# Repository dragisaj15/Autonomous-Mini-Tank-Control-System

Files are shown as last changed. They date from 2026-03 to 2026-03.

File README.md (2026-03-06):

# Autonomous Mini Tank Control System
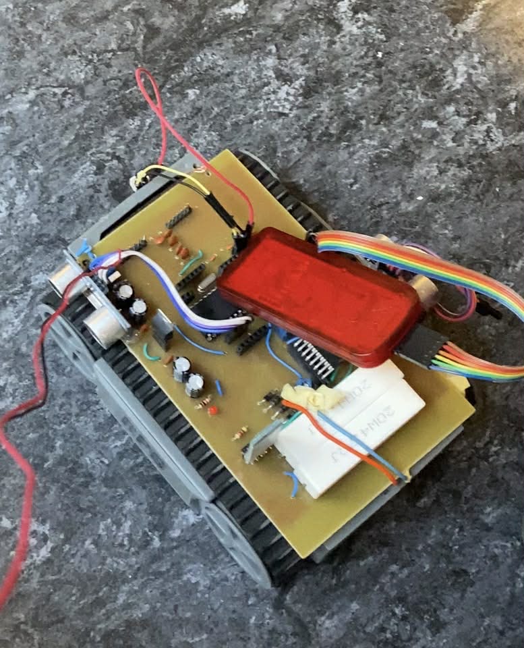
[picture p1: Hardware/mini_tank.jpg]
Assembled Mini Tank


##  Project Overview
This project involves the development of an autonomous, tracked robotic vehicle (Mini Tank) controlled by a **dsPIC30F4013** microcontroller. The system is designed to navigate its environment independently by constantly scanning for obstacles and making real-time pathfinding decisions.

The tank integrates both analog infrared and digital ultrasonic sensors to calculate distances, uses PWM to drive the motors, and is remotely activated via a Bluetooth serial (UART) connection.
## Custom PCB Design (Altium Designer)

To accommodate all necessary components, including the microcontroller, motor drivers, and sensor arrays, a custom double-sided printed circuit board (PCB) was designed.

### 2D PCB Routing
This view demonstrates the trace routing across the top (red) and bottom (blue) layers, including necessary via placements and component footprints.
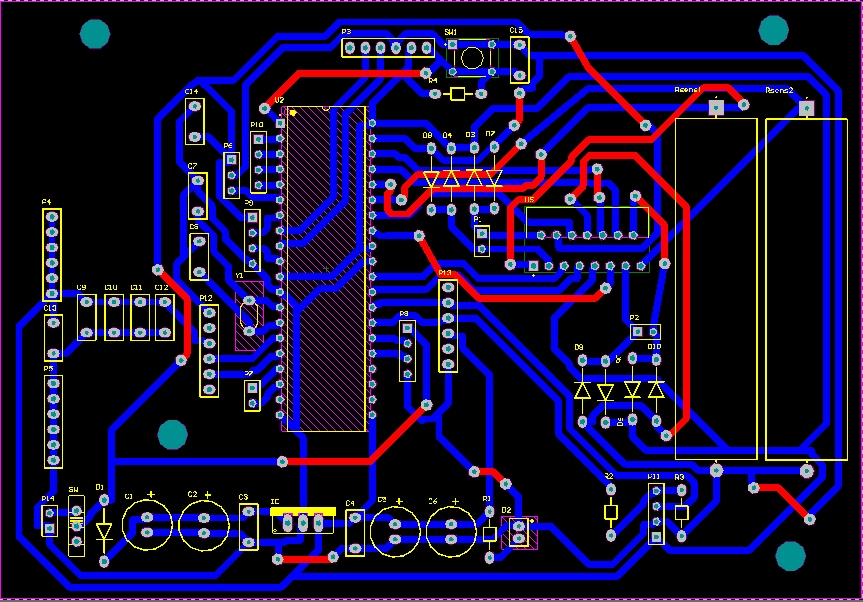
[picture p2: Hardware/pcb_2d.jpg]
2D PCB Routing


### 3D Board Visualization
The 3D model was generated to verify component placement and ensure no mechanical collisions prior to manufacturing.
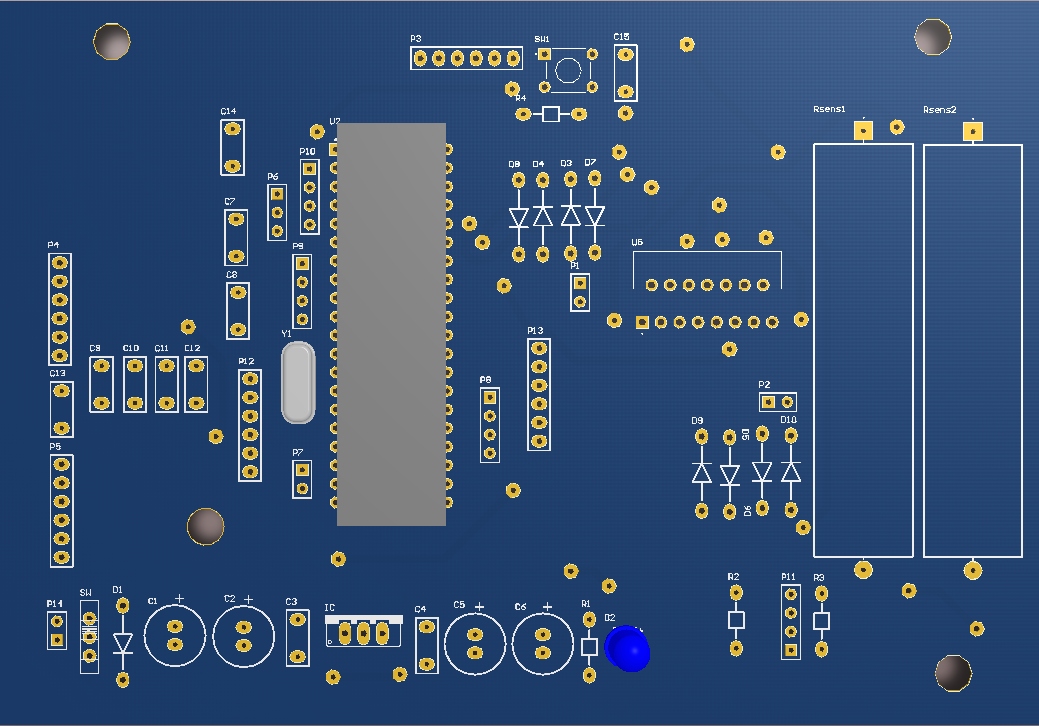
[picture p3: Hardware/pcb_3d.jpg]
3D PCB Model


##  Hardware Architecture
*   **Microcontroller:** Microchip dsPIC30F4013 (10MHz crystal, `XT_PLL4`)
*   **Sensors:**
    *   **1x Sharp GP2Y** (Analog IR Distance Sensor) - Front obstacle detection
    *   **2x HC-SR04** (Digital Ultrasonic Sensors) - Left and right obstacle detection
*   **Actuators:**
    *   DC Motors (Track drive system controlled via PWM)
*   **Communication:** Bluetooth Module (HC-05/HC-06) connected via UART2

##  Firmware & Peripheral Utilization (C Language)
The firmware relies heavily on bare-metal C programming, utilizing multiple hardware peripherals to ensure non-blocking, real-time execution:
*   **Hardware Timers & Interrupts:**
    *   `TMR1` & `TMR2`: System tick and precise delay generation (milliseconds & microseconds).
    *   `TMR3`: Base timer for Motor PWM generation.
    *   `TMR4` & `TMR5`: Dedicated timers for measuring the precise `ECHO` pulse width from the HC-SR04 sensors.
*   **12-bit ADC Module:** Configured with `_ADCInterrupt` to continuously read the analog voltage from the Sharp GP2Y sensor and convert it to distance (cm) using a non-linear power function.
*   **UART2 Module:** Configured to receive start commands (`"ON"`) via Bluetooth and transmit debugging telemetry back to the user.

##  Navigation Logic
1.  **System Standby:** The tank waits for the `"ON"` command via Bluetooth UART.
2.  **Forward Movement:** As long as the front IR sensor reads a clear path (`> 12 cm`), the tank moves forward.
3.  **Obstacle Avoidance:** If an obstacle is detected in front (`< 12 cm`), the tank stops.
4.  **Path Decision:** It compares the distances measured by the Left and Right HC-SR04 sensors. The tank will automatically rotate towards the side with more open space, recalculate, and resume forward movement.

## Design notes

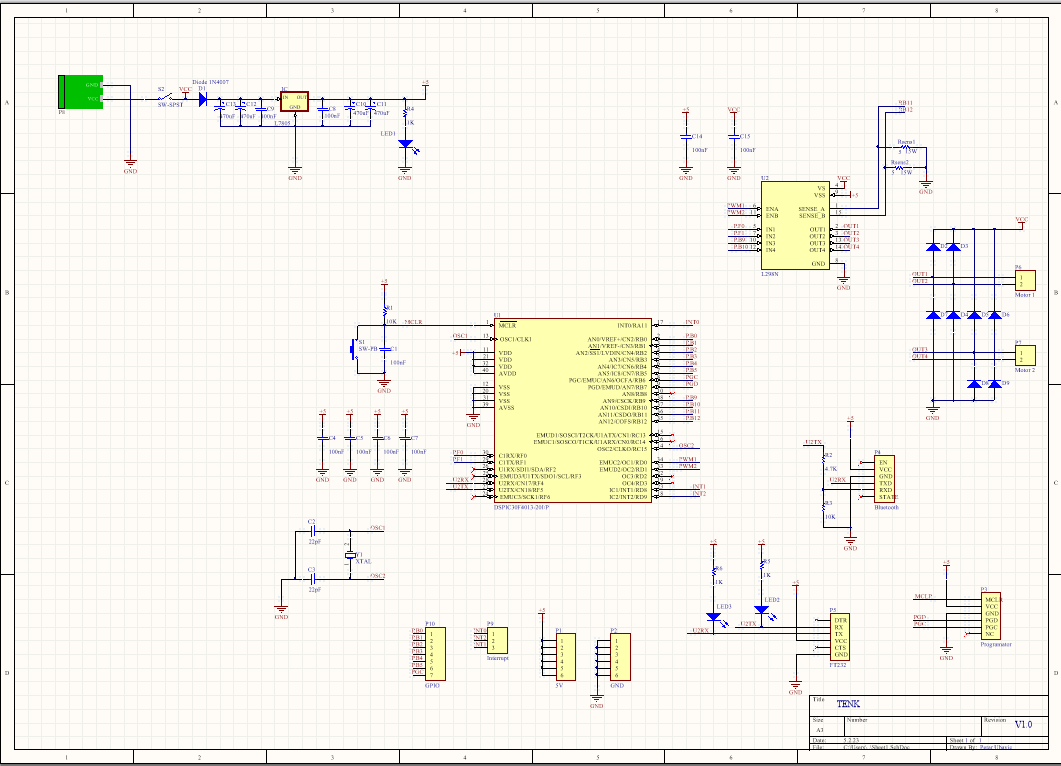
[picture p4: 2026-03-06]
Hardware/Schematic.png

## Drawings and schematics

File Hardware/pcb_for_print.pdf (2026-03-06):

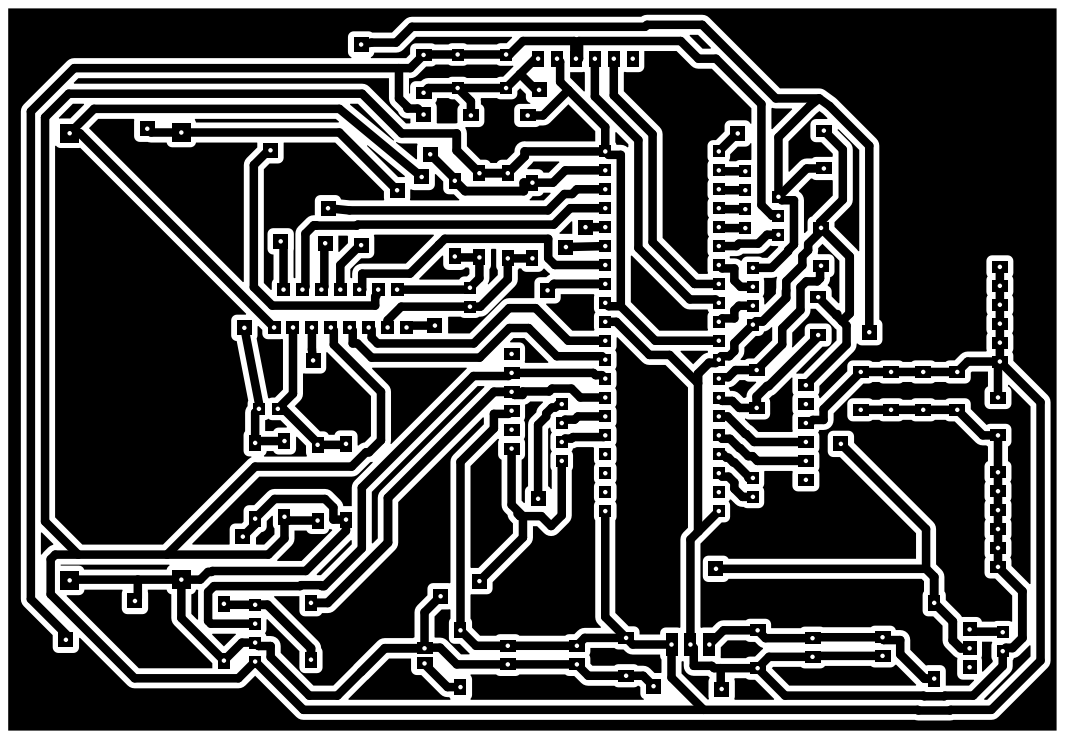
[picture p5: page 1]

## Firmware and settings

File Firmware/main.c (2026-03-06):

#include <p30fxxxx.h>
#include <stdio.h>
#include <stdlib.h>
#include <math.h>
#include "adc.h"
#include "timer.h"
#include "uart.h"
#include "hc_senzor.h"
#include "outcompare.h"
#include "pwm.h"
#include "upravljanje_motora.h"

_FOSC(CSW_FSCM_OFF & XT_PLL4); // Instruction clock is the same as the 10MHz crystal
_FWDT(WDT_OFF);                // Disable Watchdog Timer

#define SPEED_OF_SOUND (0.0343) // cm/s
#define INSTRUCTION_CLOCK_PERIOD (0.1) // us

unsigned int raw_adc0, gp2y_flag, sys_flag;
unsigned int temp_delay, temp_delay1, temp_delay2, rx_index, tempRX, temp0, analog_val;
unsigned int analog_read, echo_pulse;
int rx_buf[1];

static unsigned char timeout_sensor_2 = 0;
static float measured_distance_2 = 0;
static unsigned char timeout_sensor_1 = 0;
static float measured_distance_1 = 0;
static float distance_gp2y = 0;
static float voltage_gp2y = 0;
static int counter_us, counter_ms;

// TIMER 1 INTERRUPT ROUTINE - Every 1ms
void __attribute__ ((__interrupt__, no_auto_psv)) _T1Interrupt(void) 
{
    TMR1 = 0;
    counter_ms++;
    IFS0bits.T1IF = 0;     
}

// TIMER 2 INTERRUPT ROUTINE - Every 1us
void __attribute__ ((__interrupt__, no_auto_psv)) _T2Interrupt(void) 
{
    TMR2 = 0;
    counter_us++;
    IFS0bits.T2IF = 0;     
}

// TIMER 3 INTERRUPT ROUTINE - For PWM generation
void __attribute__ ((__interrupt__, no_auto_psv)) _T3Interrupt(void) 
{
    TMR3 = 0;
    IFS0bits.T3IF = 0;     
}

// TIMER 4 INTERRUPT ROUTINE - For the second digital ultrasonic sensor
void __attribute__ ((__interrupt__, no_auto_psv)) _T4Interrupt(void) 
{
    TMR4 = 0;
    ECHO_PIN_2 = 0;
    timeout_sensor_2 = 1;
    IFS1bits.T4IF = 0;     
}

// TIMER 5 INTERRUPT ROUTINE - For the first digital ultrasonic sensor
void __attribute__ ((__interrupt__, no_auto_psv)) _T5Interrupt(void) 
{
    TMR5 = 0;
    ECHO_PIN = 0;  
    timeout_sensor_1 = 1;
    IFS1bits.T5IF = 0;     
}

// FUNCTION PROTOTYPE - Delay in ms
static void DelayMs(int time_ms);
// FUNCTION PROTOTYPE - Delay in us
static void DelayUs(int time_us);

// UART2 INTERRUPT ROUTINE - For Bluetooth communication
void __attribute__((__interrupt__)) _U2RXInterrupt(void) 
{
    IFS1bits.U2RXIF = 0;
    tempRX = U2RXREG;
    if(tempRX != 0){
        rx_buf[rx_index] = tempRX;
        if(rx_index < 2) {
            rx_index++;
        } 
        else {
            rx_index = 0;
        }
    }
} 

// ADC INTERRUPT ROUTINE
void __attribute__((__interrupt__)) _ADCInterrupt(void) 
{
    raw_adc0 = ADCBUF0; // Read from GP2Y sensor channel
    analog_val = raw_adc0;
                                      
    IFS0bits.ADIF = 0;
} 

// DELAY FUNCTION - milliseconds
static void DelayMs(int time_ms)
{
    counter_ms = 0;
    T1CONbits.TON = 1;
    while(counter_ms < time_ms);
    T1CONbits.TON = 0;
}
                
// DELAY FUNCTION - microseconds           
static void DelayUs(int time_us)
{
    counter_us = 0;
    T2CONbits.TON = 1;
    while(counter_us < time_us);
    T2CONbits.TON = 0;
}      

// READ VOLTAGE FROM ANALOG GP2Y SENSOR AND CONVERT TO DISTANCE (IN CM)
float ReadDistance1GP2Y(){  
    // Convert analog ADC value to voltage
    voltage_gp2y = analog_val * (5.0 / 4095.0);

    // Convert voltage to distance in centimeters (based on GP2Y datasheet curve)
    distance_gp2y = 27.86 * powf(voltage_gp2y, -1.15);
    
    return distance_gp2y;
}

// READ VALUE FROM FIRST ULTRASONIC SENSOR
float ReadDistance1() {
    // Generate a 10us trigger pulse
    TRIGGER_PIN = 1;
    DelayUs(3);
    TRIGGER_PIN = 0;
    DelayUs(3);
    
    // Wait for ECHO pin to go high
    while (ECHO_PIN == 0);
    TMR5 = 0;              
    IFS1bits.T5IF = 0;
    T5CONbits.TON = 1;    // Start Timer 5
    
    // Measure the width of the ECHO signal
    while (ECHO_PIN == 1);
    T5CONbits.TON = 0;  // Stop Timer 5, measurement complete
    
    unsigned int measured_time_1; 
    if(timeout_sensor_1 == 1)     // If timeout occurred (no object in range)
    {
        measured_time_1 = TMR5_period;
        timeout_sensor_1 = 0;
    }
    else                            // Signal returned successfully
    {
        measured_time_1 = TMR5;
    }
    TMR5 = 0;
   
    // Calculate distance based on speed of sound
    measured_distance_1 = (measured_time_1 * INSTRUCTION_CLOCK_PERIOD) / 2.0 * SPEED_OF_SOUND;        
    return measured_distance_1;
} 

// READ VALUE FROM SECOND ULTRASONIC SENSOR
float ReadDistance2() {
    // Generate a 10us trigger pulse
    TRIGGER_PIN_2 = 1;
    DelayUs(3);
    TRIGGER_PIN_2 = 0;
    DelayUs(3);
    
    // Wait for ECHO pin to go high
    while (ECHO_PIN_2 == 0);
    TMR4 = 0;
    IFS1bits.T4IF = 0;
    T4CONbits.TON = 1; 
    
    // Measure the width of the ECHO signal
    while (ECHO_PIN_2 == 1);
    T4CONbits.TON = 0;  // Stop Timer 4, measurement complete
    
    unsigned int measured_time_2; 
    if(timeout_sensor_2 == 1)     // If timeout occurred
    {
        measured_time_2 = TMR4_period;
        timeout_sensor_2 = 0;
    }
    else                            // Signal returned successfully
    {
        measured_time_2 = TMR4;
    }
    TMR4 = 0;

    // Calculate distance based on speed of sound
    measured_distance_2 = (measured_time_2 * INSTRUCTION_CLOCK_PERIOD) / 2.0 * SPEED_OF_SOUND;        
    return measured_distance_2;
} 

// START SYSTEM - System activates when "ON" is received via Bluetooth
void start(){
    if(rx_buf[0] == 'O' && rx_buf[1] == 'N') {
            sys_flag = 1;
            WriteUART2(10);
            RS232_putst2("STARTING"); // Notify via Bluetooth
            DelayMs(2000);
    }
}


int main(int argc, char** argv) {
    
    // Initial stabilization delays
    for(temp_delay1=0; temp_delay1<10000; temp_delay1++);
    for(temp_delay=0; temp_delay<60000; temp_delay++);
    
    sys_flag = 0;
    
    // Hardware Initializations
    Init_T1();
    Init_T2();
    Init_T3();
    Init_T4();
    Init_T5();
    
    ConfigureADCPins();
    ADCinit();
    ADCON1bits.ADON = 1; // Start AD conversion 
    
    ConfigureHC_sensor();
    initUART1();
    initUART2(); // Bluetooth UART
    initPWM();   // Motor control PWM
    
	while(1)
	{
        start();    
        
        if (sys_flag == 1) {
            
            distance_gp2y = ReadDistance1GP2Y();
            WriteUART2(10);
            
            measured_distance_1 = ReadDistance1();
            measured_distance_2 = ReadDistance2();
        
            /*
            // PRINT MEASURED SENSOR VALUES TO BLUETOOTH
            char buffer[20];
            int i;

            // Print Sensor 1 to BT
            sprintf(buffer, "Sensor 1: %.2f cm\r", (double)measured_distance_1);
            for (i = 0; i < 20; i++) {
                WriteUART2(buffer[i]);
            }
              
            // Print Sensor 2 to BT  
            sprintf(buffer, "Sensor 2: %.2f cm\r\n", (double)measured_distance_2);
            for (i = 0; i < 20; i++) {
                WriteUART2(buffer[i]);
            } 
            
            // Print GP2Y to BT
            sprintf(buffer, "Sensor GP2Y: %.2f cm\r", (double)distance_gp2y);
            for (i = 0; i < 20; i++) {
                WriteUART2(buffer[i]);
            } 
            */
       
            // NAVIGATION ALGORITHM:
            // The tank moves forward until an obstacle is detected in front.
            // When an obstacle is detected, it compares the values of the left and right sensors 
            // to decide the best direction to turn.
            
            if(distance_gp2y >= 12) {
                pravo(); // Move forward
                
            } else if (distance_gp2y < 12 && (measured_distance_2 <= measured_distance_1)){
                stani(); // Stop
                DelayMs(500);
                levo();  // Turn left
                DelayMs(1200);
                stani(); // Stop
                DelayMs(100);
                
            } else if (distance_gp2y < 12 && (measured_distance_1 < measured_distance_2)) {
                stani(); // Stop
                DelayMs(500);
                desno(); // Turn right
                DelayMs(1200);
                stani(); // Stop
                DelayMs(100);
                
            } else {
                stani(); // Stop default
            } 
        } // end if sys_flag
    } // end while    
    
    return (EXIT_SUCCESS);
}

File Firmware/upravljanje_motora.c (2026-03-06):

#include "upravljanje_motora.h"
#include "pwm.h"
#include "uart.h"
#include <p30fxxxx.h>

void pravo()
{
    
    LATFbits.LATF0=1; //za smer prvog motora
    LATFbits.LATF1=0; 
        
    LATBbits.LATB9=1; //za smer drugog motora
    LATBbits.LATB10=0; 
    
    PWM1(450); //PWM 1 i PWM 2 nisu postavljeni na iste vrednosti, jer jedan motor malo slabije radi, pa smo empirjiski dosli do ovih optimalnih vrednosti
    PWM2(480);
    
    RS232_putst2("Idem pravo");
}

void levo()
{
    //DESNI MOTOR IDE NAPRED, A LEVI NAZAD
    LATFbits.LATF0=1; //za smer prvog motora
    LATFbits.LATF1=0; 
        
    LATBbits.LATB9=0; //za smer drugog motora
    LATBbits.LATB10=1; 
    
    PWM1(480); //PWM NIJE POSTAVLJEN JEDNAKO KAKO BI MOTOR BOLJE SKRETAO
    PWM2(450);
    
    RS232_putst2("Idem levo");
}

void desno()
{
    
    LATFbits.LATF0=0; //za smer prvog motora
    LATFbits.LATF1=1; 
        
    LATBbits.LATB9=1; //za smer drugog motora
    LATBbits.LATB10=0; 
    
    PWM1(470);
    PWM2(470);
     
    RS232_putst2("Idem desno");
    
}
void stani()
{
    //MOTORI SU UGASENI
    LATFbits.LATF0=0; 
    LATFbits.LATF1=0; 
        
    LATBbits.LATB9=0; 
    LATBbits.LATB10=0; 
    
    PWM1(300);
    PWM2(300);
    
}

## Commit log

2026-03-06 Update and rename adc.c to Firmware/adc.c
2026-03-06 Update and rename adc.h to Firmware/adc.h
2026-03-06 Update and rename pwm.c to Firmware/pwm.c
2026-03-06 Update and rename pwm.h to Firmware/pwm.h
2026-03-06 Update and rename uart.c to Firmware/uart.c
2026-03-06 Update and rename timer.c to Firmware/timer.c
2026-03-06 Update and rename uart.h to Firmware/uart.h
2026-03-06 Update and rename timer.h to Firmware/timer.h
